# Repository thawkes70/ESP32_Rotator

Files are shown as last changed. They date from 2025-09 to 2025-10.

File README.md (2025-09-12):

# ESP32 Rotator Controller

An ESP32-based dual-axis (Azimuth/Elevation) antenna rotator controller.  
Designed for satellite tracking, radio astronomy, and other applications requiring precise pointing.

## ✨ Features
- **Dual-axis control** (Azimuth & Elevation)
- **Stepper motor drivers** (DM556T or compatible)
- **FastAccelStepper** library for smooth motion
- **Magnetometer/accelerometer (LSM303)** feedback for position sensing
- **Optical limit switches** for safe homing
- **Web UI** for monitoring and manual control
  - Displays live AZ/EL readings
  - Absolute and Relative move commands
  - ROTCL Connection
  - Emergency Stop button
  - Reset & Homing controls
  - OTA Updates
- **rotctl protocol support** over Wi-Fi (Hamlib compatible on port 4533)
- **FreeRTOS task-based design** (separate cores for motor control, sensors, networking, etc.)

## 🛠️ Hardware Requirements
- ESP32 development board (tested on LOLIN32 D32)
- NEMA 34 stepper motors        
- DM556T stepper drivers
- Planetary gearboxes (50:1 or 72:1)
- LSM303 accelerometer + magnetometer module
- Magnetic Hall Effect endstop switches for AZ/EL
- Power supply sized for motors

## 🚀 Getting Started

### Build & Upload (PlatformIO)
1. Clone this repository:
   ```bash
   git clone https://github.com/<your-username>/ESP32_rotator.git
   cd ESP32_rotator
2. Open in VS Code + PlatformIO
3. Connect your ESP32 board.
4. Build & upload:

##Web UI
Connect to ESP32’s Wi-Fi network or your LAN.
Open the ESP32’s IP in a browser (default port 80).

📖 TODO / Roadmap
 Improve sensor filtering (smoothing on LSM303 data)
 Add configurable calibration offsets
 Enhance error handling & watchdog recovery
 Document FreeRTOS task layout and core assignments

📝 License
MIT License – feel free to use, modify, and share.

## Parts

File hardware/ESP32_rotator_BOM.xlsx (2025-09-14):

Item | Qty | Cost each (AUD) | Total Cost (AUD) | Link
Stepper Motor | 3 | $80.00 | $240.00 | https://www.ebay.com.au/itm/177239729438
72:1 Reduction Gearboxes Ratio 72 to 1, 14 Input 14 Output | 3 | $122.00 | $366.00 | https://www.aliexpress.com/item/1005008987966902.html
DM556 Stepper Driver | 3 | $22.00 | $66.00 | https://www.aliexpress.com/item/1005005264850020.html
48V 10A PSU | 1 | $90.00 | $90.00 | https://www.aliexpress.com/item/1005007051027312.html
12V 3A PSU | 1 | $20.00 | $20.00 | https://www.aliexpress.com/item/1005007347340166.html
ESP32 Lolin32 | 1 |  | $0.00 | https://www.ebay.com.au/itm/356799255814?_skw=lolin32&itmmeta=01K556596FPF4M019G6E4PPA0J
ESP32 Breakout Board | 1 | $22.00 | $22.00 | https://www.amazon.com.au/dp/B0DT48T7CB?ref=ppx_yo2ov_dt_b_fed_asin_title
Connectors for enclosure | 5 | $16.00 | $80.00 | https://www.aliexpress.com/item/1005008968948261.html
Elactronics Enclosure | 1 | $98.00 | $98.00 | https://www.amazon.com.au/dp/B0D2K2G3KS?ref=ppx_yo2ov_dt_b_fed_asin_title&th=1
A3144E Hall effect sensor | 2 | $1.00 | $2.00 | https://www.aliexpress.com/item/1005005970013535.html
Wemos D1 ESP8266 | 1 | $5.00 | $5.00 | https://www.amazon.com.au/ESP8266-ESP-12-ESP-12F-NodeMcu-Development/dp/B0CCVGP1TK
LSM303 Magnetometer | 1 | $10.00 | $10.00 | https://www.ebay.com.au/itm/303134438854
Shielded Cable |  |  | $0.00 | 4 core 20AWG shileded cable I had in stock
100 x 100mm Square Hollow Section | 2 | $20.00 | $40.00 | Local Steel Supplier
75 x 5mm Flat Bar | 3 | $10.00 | $30.00 | Local Steel Supplier
Thrust Bearing 30x60x21mm | 1 | $15.00 | $15.00 | https://www.aliexpress.com/item/1005008463633484.html
Flange Coupling 14mm | 3 | $25.00 | $75.00 | https://www.aliexpress.com/item/32842274110.html
M4, M6, M8 Bolts, Washers |  |  | $0.00 | Had Various mounting hardware in stock
M4, M6, M8 Rivnuts |  |  | $0.00 | Had Various mounting hardware in stock
Matt Black Spray Paint | 2 | $5.00 | $10.00 | Local Hardware
Pole Mount | 1 | $0.00 | $0.00 | Came free with 2.3m mesh dish (Facebook Marketplace)
3D Printed Items | 1 | $0.00 | $0.00 | Use ASA for it's UV satbilised properties
Cable Glands | 6 | $1.00 | $6.00 | https://www.amazon.com.au/dp/B0DRFTY6NK?ref=ppx_yo2ov_dt_b_fed_asin_title
Junction Box 1 115 x 90 x 55 | 1 | $20.00 | $20.00 | https://www.jaycar.com.au/sealed-polycarbonate-enclosure-115-x-90-x-55/p/HB6217
Junction Box 2 82 x 80 x 55mm | 1 | $15.00 | $15.00 | https://www.jaycar.com.au/sealed-polycarbonate-enclosure-82-x-80-x-55mm/p/HB6230
Magnets for end stop switch | 2 | $1.00 | $2.00 | https://www.amazon.com.au/dp/B0CM3KX5BC?ref=ppx_yo2ov_dt_b_fed_asin_title
Total |  |  | $1212.00

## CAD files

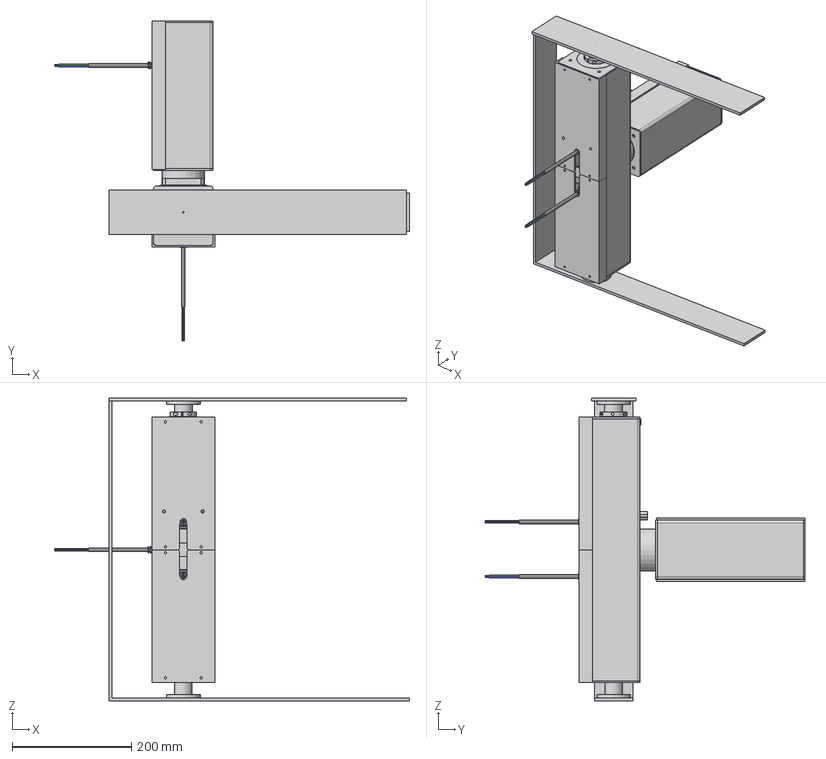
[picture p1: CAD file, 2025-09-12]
hardware/step/Rotator_MKIII v23.step
596.4 x 538.0 x 509.0 mm
Reduction Gearbox_E1
34HE31-6004S
Reduction Gearbox_E2
34HE31-6004S_1
Reduction Gearbox_AZ1
34HE31-6004S_2
EL_Housing (1)
Flange_E1
Flange_E2
Flange_AZ
EL_Endcap2
EL_Endcap2 (1)
AZ_Housing
AZ_Endcap
AZ_Endcap2
Thrust Bearing
EL_EndStop_Ring1
EL_Endstop_Ring2
AZ_Bearing_Cover
EL_Arm
EL_Top_Cap
AZ_Top_Cap
AZ_Endstop_Magnet
EL_Top_Cap (2)

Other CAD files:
hardware/fusion360/Rotator_MKIII v23.f3d

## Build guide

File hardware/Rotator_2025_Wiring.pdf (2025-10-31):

# ESP32 AZ/EL ROTATOR

# ESP32 AZ/EL ROTATOR

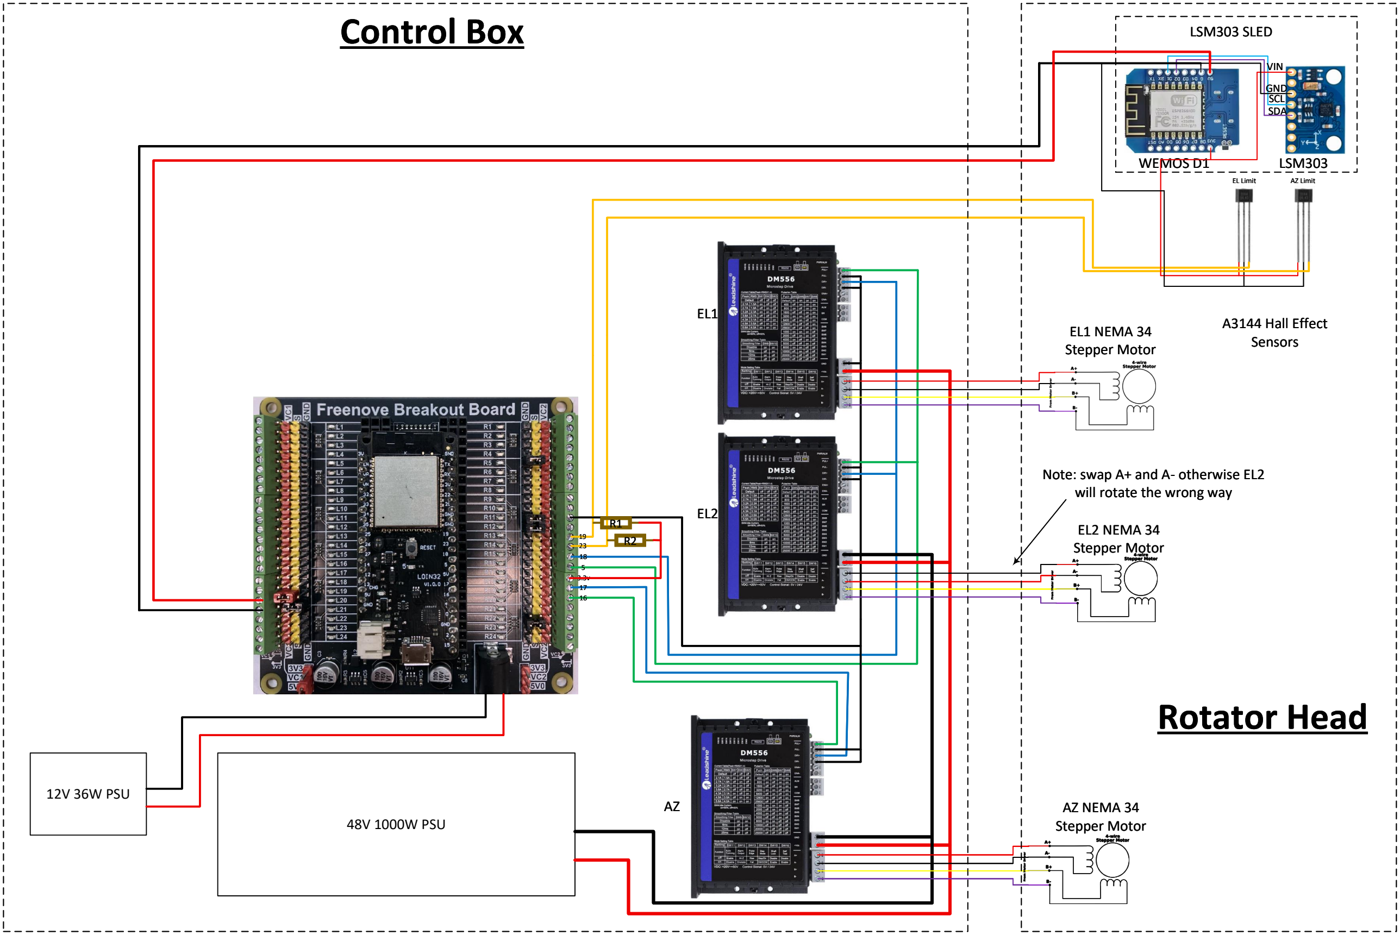
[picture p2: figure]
EL Limit; AZ Limit; 48V 1000W PSU; 12V 36W PSU; EL1 NEMA 34 Stepper Motor; EL2 NEMA 34 Stepper Motor; AZ NEMA 34 Stepper Motor; SCL SDA; GND; VIN; LSM303; Control Box; A3144 Hall Effect Sensors; WEMOS D1; Note: swap A+ and A- otherwise EL2 will rotate the wrong way; Rotator Head; LSM303 SLED

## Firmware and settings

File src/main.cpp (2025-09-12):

// ESP32 sketch adapted to receive AZ/EL data from Nano over Serial
#include <Arduino.h>
#include <WiFi.h>
#include <FastAccelStepper.h>
#include <EEPROM.h>
#include "WebInterface.h"
#include "WebLogger.h"
#include "MotorControl.h"
#include "esp_task_wdt.h"
#include "rotctl_server.h"
#include "Homing.h"
#include <ArduinoOTA.h>
#include "LSM303Receiver.h"
#include "Calibration.h"
#include <ElegantOTA.h>

// --- Hardware and Firmware Info for ElegantOTA ---
const char* HARDWARE_ID = "ESP32 Rotator";
const char* FIRMWARE_VERSION = "v1.2.0";  // update this with each firmware release

// === Wi-Fi Credentials ===
const char* ssid = "";
const char* password = "";

// === TCP Server ===
WiFiClient client;

// === Web Logger ===
WebLogger webLogger;

// === Stepper Motor Pins ===
#define AZ_STEP_PIN 12
#define AZ_DIR_PIN 13
#define EL1_STEP_PIN 5
#define EL1_DIR_PIN 18
#define EL2_STEP_PIN 26
#define EL2_DIR_PIN 27

// === Limit Switch Pins ===
const int AZ_LIMIT_PIN = 23;
const int EL_LIMIT_PIN = 19;

// === Limits and Mechanical Constants ===
float motorStepAngle = 1.8;
int gearRatio = 72;
int microstepsPerRevolution = 400;
float stepsPerRevolution = microstepsPerRevolution * gearRatio;
float stepsPerDegree = stepsPerRevolution / 360.0;

bool useLSMforEl = false;  // default: use stepper

// === State ===

bool elGangedDrive = true;
float currentAzimuth = 0.0, currentElevation = 0.0;


bool rotctlConnected = false;

LSM303Receiver lsmReceiver(4210);  // 4210 = UDP port


Calibration calib(&lsmReceiver);



// === FastAccelStepper Setup ===
FastAccelStepperEngine engine = FastAccelStepperEngine();
FastAccelStepper *azMotor = NULL;
FastAccelStepper *elMotor1 = NULL;
FastAccelStepper *elMotor2 = NULL;

// === Task Handle ===
TaskHandle_t StepperTask;

// === Stepper Core Task ===
void stepperTaskCode(void *pvParameters) {
  esp_task_wdt_add(NULL);
  for (;;) {
    esp_task_wdt_reset();
    vTaskDelay(pdMS_TO_TICKS(1)); // just yield a little time
  }
}

// === Setup Function ===
void setup() {
    Serial.begin(115200);
    delay(100);

    // ----------------------
    // Limit Switch Pins
    // ----------------------
    pinMode(AZ_LIMIT_PIN, INPUT);
    pinMode(EL_LIMIT_PIN, INPUT);

    // ----------------------
    // Wi-Fi
    // ----------------------
    WiFi.begin(ssid, password);
    Serial.print("Connecting to Wi-Fi");
    while (WiFi.status() != WL_CONNECTED) {
        delay(500);
        Serial.print(".");
    }
    Serial.println();
    Serial.print("Wi-Fi connected, IP = ");
    Serial.println(WiFi.localIP());

    // ----------------------
    // Start LSM303Receiver
    // ----------------------
    lsmReceiver.begin();

    // ----------------------
    // Web server
    // ----------------------
    setupWebServer();

    // ----------------------
    // Initialize FastAccelStepper engine
    // ----------------------
    engine.init();

    azMotor = engine.stepperConnectToPin(AZ_STEP_PIN);
    if (azMotor) {
        azMotor->setDirectionPin(AZ_DIR_PIN);
        azMotor->setSpeedInHz(800);
        azMotor->setAcceleration(1000);
    }

    elMotor1 = engine.stepperConnectToPin(EL1_STEP_PIN);
    if (elMotor1) {
        elMotor1->setDirectionPin(EL1_DIR_PIN);
        elMotor1->setSpeedInHz(800);
        elMotor1->setAcceleration(1000);
    }

    elMotor2 = engine.stepperConnectToPin(EL2_STEP_PIN);
    if (elMotor2) {
        elMotor2->setDirectionPin(EL2_DIR_PIN);
        elMotor2->setSpeedInHz(800);
        elMotor2->setAcceleration(1000);
    }

    // ----------------------
    // Stepper core task
    // ----------------------
    xTaskCreatePinnedToCore(stepperTaskCode, "StepperTask", 10000, NULL, 1, &StepperTask, 0);

    // ----------------------
    // Home rotator
    // ----------------------
    homeAzimuth();
   // homeElevation();

    // ----------------------
    // Start rotctl server
    // ----------------------
    startRotctlServer();

    Serial.println("Setup complete.");
}

void loop() {
    // ----------------------
    // Web UI
    // ----------------------
   // handleWebServer();
    // ----------------------
    // Homing updates
    // ----------------------
    updateHoming();

    // ----------------------
    // Update stepper positions to rotctl
    // ----------------------
   // --- Report current rotator position ---
    float azPos = stepsToAz(azMotor->getCurrentPosition());  // always from stepper

    float elPos;
    if (useLSMforEl) {
        // Use LSM-corrected elevation
        elPos = lsmReceiver.getElCorrected();
    } else {
        // Use stepper position
        elPos = stepsToEl(elMotor1->getCurrentPosition());
    }

    // Update rotctl position
    setRotatorPosition(azPos, elPos);


    // ----------------------
    // Update LSM303Receiver
    // ----------------------
    lsmReceiver.update();
    
    // ----------------------
    // Update LSM303Receiver
    // ----------------------
     if (calib.isRunning()) {
        calib.update();
    }
   

}

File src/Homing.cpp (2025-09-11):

#include "Homing.h"
extern LSM303Receiver lsmReceiver;

// --- Homing state variables ---
HomingStage homingStage = HOMING_IDLE;
bool azHomed = false;
bool elHomed = false;
int azHomingDir = -1; // example: CCW
int elHomingDir = -1; // example: DOWN

// --- Debounced AZ limit globals ---
unsigned long azLimitLastChange = 0;
const unsigned long AZ_LIMIT_DEBOUNCE_MS = 5;  // ms
bool azLimitState = false; // debounced state

// --- Debounced EL limit globals ---
unsigned long elLimitLastChange = 0;
const unsigned long EL_LIMIT_DEBOUNCE_MS = 5;  // ms
bool elLimitState = false; // debounced state

//Homing delay globals
unsigned long elStopStartTime = 0;
bool elStopStarted = false;

void updateAzLimit() {
    bool raw = digitalRead(AZ_LIMIT_PIN) == LOW;
    unsigned long now = millis();
    if (raw != azLimitState && now - azLimitLastChange >= AZ_LIMIT_DEBOUNCE_MS) {
        azLimitState = raw;
        azLimitLastChange = now;
        Serial.print("[AZ LIMIT] "); Serial.println(azLimitState ? "TRIGGERED" : "CLEAR");
    }
}

void updateElLimit() {
    bool raw = digitalRead(EL_LIMIT_PIN) == LOW;
    unsigned long now = millis();
    if (raw != elLimitState && now - elLimitLastChange >= EL_LIMIT_DEBOUNCE_MS) {
        elLimitState = raw;
        elLimitLastChange = now;
        Serial.print("[EL LIMIT] "); Serial.println(elLimitState ? "TRIGGERED" : "CLEAR");
    }
}

void homeAzimuth() {
    if (!azMotor) return;
    homingStage = HOMING_AZ_PRE_HOME;
    azHomed = false;
    long target = azHomingDir * MAX_HOMING_STEPS;
    Serial.println("[HOMING] Starting azimuth homing...");
    Serial.print("[HOMING] Moving AZ motor towards "); 
    Serial.print(azHomingDir > 0 ? "CW" : "CCW");
    Serial.print(" for max "); Serial.print(MAX_HOMING_STEPS); Serial.println(" steps");
    azMotor->moveTo(target, false);
}

void homeElevation() {
    if (!elMotor1) return;
    homingStage = HOMING_EL_MOVING;
    elHomed = false;
    long target = elHomingDir * MAX_HOMING_STEPS;
    Serial.println("[HOMING] Starting elevation homing...");
    Serial.print("[HOMING] Moving EL motors towards "); 
    Serial.print(elHomingDir > 0 ? "UP" : "DOWN");
    Serial.print(" for max "); Serial.print(MAX_HOMING_STEPS); Serial.println(" steps");
    elMotor1->moveTo(target, false);
    if (elGangedDrive && elMotor2) elMotor2->moveTo(target, false);
}

void updateHoming() {
    // --- Update limit switches ---
    updateAzLimit();
    updateElLimit();

    switch (homingStage) {
        case HOMING_AZ_PRE_HOME:
        // Check if we need to move az to safe pre-home position
        {
            float azDeg = stepsToAz(azMotor->getCurrentPosition());
            if (azDeg < 0 || azDeg > 360) {
                WEB_LOG_WARNINGF("[HOMING]", "AZ out of range (%.1f°), moving to 180° before homing", azDeg);
                moveAzimuthToPosition(180.0);  // queue movement
            } else {
                WEB_LOG_INFO("[HOMING]", "AZ within safe range, skipping pre-home move");
                homingStage = HOMING_AZ_MOVING; // move on to normal az homing
            }
        }

        // Non-blocking check: only advance when az has finished moving
        if (!azMotor->isRunning()) {
            homingStage = HOMING_AZ_MOVING;
        }
        break;

        case HOMING_AZ_MOVING:
        if (azLimitState) {  // debounced limit triggered
            azMotor->stopMove();
            delay(800);   // allow motion to fully cease
            azMotor->setCurrentPosition(0);  // reset home
            azHomed = true;
            Serial.println("[HOMING] Azimuth limit reached, position set to 0");
            WEB_LOG_INFO("[HOMING]", "Azimuth limit reached, position set to 0");
            homeElevation();  // move to elevation homing next
        }
        break;


/*        case HOMING_EL_MOVING:
        if (!azHomed) break; // safety: wait until azimuth is homed
        if (elLimitState) {
            // Stop motors
            elMotor1->stopMove();
            delay(800);   // allow motion to fully cease
            elMotor1->setCurrentPosition(0);
            if (elGangedDrive && elMotor2) elMotor2->setCurrentPosition(0);

            // Store home reference: horizon = 0°
            float rawEl = lsmReceiver.getElevation();  
            lsmReceiver.setElHomeRaw(90.0f - rawEl);  
            lsmReceiver.resetElSmoothing();          

            elHomed = true;

            Serial.printf("[HOMING] Elevation homed. Raw=%.2f, Corrected=%.2f\n",
                            lsmReceiver.getElevation(), lsmReceiver.getElCorrected());
            Serial.println("[HOMING] Elevation limit reached, position set to 0");

            homingStage = HOMING_COMPLETE;

            // Move to 90° (zenith) after homing
            moveElevationDeg(90.0f);
            Serial.println("[HOMING] Elevation homed, moving to 90 degrees...");
            Serial.println("[HOMING] Homing sequence complete!");
        }
        break;
*/


            case HOMING_EL_MOVING:
                if (!azHomed) break; // safety: wait until azimuth is homed
                if (elLimitState) {
                    if (!elStopStarted) {
                        // Stop the motor and record the time
                        elMotor1->stopMove();
                        if (elGangedDrive && elMotor2) elMotor2->stopMove();
                        elStopStartTime = millis();
                        elStopStarted = true;
                        break;  // exit to next loop iteration
                    }

                    // Wait non-blocking for 800ms
                    if (millis() - elStopStartTime < 800) break;

                    // Now safe to reset position counters
                    elMotor1->setCurrentPosition(0);
                    if (elGangedDrive && elMotor2) elMotor2->setCurrentPosition(0);

                    lsmReceiver.setElHomeRaw(lsmReceiver.getElevation());  // store raw home value
                    lsmReceiver.resetElSmoothing();                        // reset smoothing

                    elHomed = true;
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

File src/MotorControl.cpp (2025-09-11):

#include "MotorControl.h"
#include "WebLogger.h"  // Ensure logging works
#include "MotorControl.h"
#include "Calibration.h"
#include "WebInterface.h"

extern Calibration calib;


// Azimuth control
void moveAzimuthDeg(float deg) {
    if (!azMotor) return;
    float originalDeg = deg;
    long steps = deg * stepsPerDegree;
    azMotor->move(steps);
    WEB_LOG_DEBUGF("Motor", "moveAzimuthDeg called: %f deg -> %ld steps", deg, steps);
}


void moveElevationDeg(float deg) {
    if (!elMotor1 || !elMotor2) return;
    float originalDeg = deg;
    long steps = deg * stepsPerDegree;
    elMotor1->move(steps);
    if (elGangedDrive && elMotor2) elMotor2->move(steps);
    WEB_LOG_DEBUGF("Motor", "moveElevationDeg called: %f deg -> %ld steps", deg, steps);
}



// MoveTo() version
void moveAzimuthToPosition(float degrees) {
    float originalDeg = degrees;
    long targetSteps = azToSteps(degrees);
    azMotor->moveTo(targetSteps);
}

void moveElevationToPosition(float degrees) {
    float originalDeg = degrees;
    long targetSteps = elToSteps(degrees);
    if (elGangedDrive) {
        elMotor1->moveTo(targetSteps);
        elMotor2->moveTo(targetSteps);
    } else {
        elMotor1->moveTo(targetSteps);
    }
}

void emergencyStop() {
  if (azMotor) azMotor->forceStop();
  if (elMotor1) elMotor1->forceStop();
  if (elMotor2) elMotor2->forceStop();
  calib.reset();
  azHomed = false;
  elHomed = false;

  WEB_LOG_WARN("Motor","Emergency stop executed");
}
void azMotorStop() {
  if (azMotor) azMotor->forceStop();
}

void elMotorStop() {
  if (elMotor1) elMotor1->forceStop();
  if (elGangedDrive && elMotor2) elMotor2->forceStop();
}
bool areMotorsReady() {
    bool azReady = (azMotor && !azMotor->isRunning());
    bool el1Ready = (elMotor1 && !elMotor1->isRunning());
    bool el2Ready = (elMotor2 && !elMotor2->isRunning());

    return azReady && el1Ready && el2Ready;
}

// Unit conversions
long azToSteps(float az) {
  return az * stepsPerDegree;
}

float stepsToAz(long steps) {
  return steps / stepsPerDegree;
}

long elToSteps(float el) {
  return el * stepsPerDegree;
}

float stepsToEl(long steps) {
  return steps / stepsPerDegree;
}

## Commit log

2025-09-12 Added 3D files
    [Rotator_MKIII v23.f3d, Rotator_MKIII v23.step]
2025-09-14 BOM Draft
    [ESP32_rotator_BOM.xlsx]
